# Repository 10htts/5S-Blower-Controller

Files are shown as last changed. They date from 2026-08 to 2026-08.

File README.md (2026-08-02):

# 5S Blower Controller

Open-source reference controller for a two-wire brushed-DC blower powered by a removable 5-series lithium-ion battery (approximately 15–21 V). The design uses a protected low-side N-MOSFET PWM stage, soft start, trigger filtering, voltage/current/temperature protection, an external physical fuse, and a latched fault requiring trigger release.

**Status: CAD CHECKS PASS; NOT YET APPROVED TO ORDER.** KiCad 10 reports zero DRC violations, zero unconnected items, zero schematic-parity issues, and zero ERC errors or warnings. The PCBWay review ZIP is generated, but motor, fuse, mechanical, transient, thermal, and first-article validation remain open. No regulatory certification is claimed.

See [architecture](docs/architecture.md), [wiring](docs/wiring.md), [safety](docs/safety.md), and [revision status](docs/revision-status.md). Firmware tests are host-side and do not replace hardware bring-up.

## Open and edit in KiCad

Open `hardware/blower-controller.kicad_pro` using **File → Open Existing Project** in KiCad. The project contains the editable schematic and PCB.

The canonical KiCad files are generated by `scripts/build_board.py`. A later regeneration will overwrite direct edits to the generated schematic and PCB, so save experimental manual edits under a different project name or port accepted changes into the generator and routing-repair sources.

## Rebuild and export

Run the deterministic board build with KiCad's bundled Python, then generate the current PCBWay review package:

```powershell
& "C:\Program Files\KiCad\10.0\bin\python.exe" scripts\build_board.py
python scripts\export_manufacturing.py --kicad-cli "C:\Program Files\KiCad\10.0\bin\kicad-cli.exe"
```

The current package is `manufacturing/pcbway-review-revC.zip`. It is suitable for PCBWay's Gerber viewer or quotation review, not authorization to place an order.

## Licensing

Hardware is licensed under CERN-OHL-S-2.0 (`LICENSE`). Firmware is GPLv3-or-later (`firmware/LICENSE`).

## Planned validation

Measure stall/start/run current, battery connector polarity, motor inductance, housing fit, fuse interruption behavior, and thermal rise before selecting production thresholds or ordering PCBs.

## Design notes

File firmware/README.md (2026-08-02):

# Firmware

Host-testable reference state machine. Build with a C++17 compiler when targeting hardware; constants are centralized in `src/config.h`. The controller retains soft-start progress across calls, latches protection trips until trigger release, applies the configured undervoltage restart hysteresis, and fails safe on invalid engineering inputs.

`Inputs::trigger` is normalized active-high. The board input is electrically active-low, so the target-specific hardware layer must debounce and invert the pin before calling `Controller::step`. That layer must also configure PWM safe-off at reset, the ATtiny1616 watchdog and brown-out detector, ADC scaling/filtering, periodic scheduling, and gate-output shutdown on missed deadlines. Those target-specific pieces and the final thresholds remain release blockers; this portable code does not claim a verified MCU image or pinout.

`firmware/tests/controller_test.cpp` exercises the compiled state machine when a C++ compiler is available. The Python test suite skips that executable test on hosts without a compiler; CI and release validation must run it with warnings treated as errors.

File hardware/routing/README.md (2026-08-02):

# Rev C routing source

`revC-freerouting.ses` is the accepted Specctra session produced with official
Freerouting 2.2.4 from the `--power-stage-only` board generated by
`scripts/build_board.py`.

The default board build imports that session and then runs
`scripts/repair_freeroute_candidate.py`. The repair script records the reviewed
track, via, ground-stitch, zone-corridor, and two footprint-placement changes
that close the remaining imported-route gaps. KiCad then refills zones and runs
strict DRC with schematic parity; a failing check stops the build.

The post-route repair also keeps the C12/C16 GND stitch outside the 0603 solder
pads. The build explicitly enables missing-courtyard and track-endpoint centering
on vias as errors before DRC.

This routing source makes the CAD result reproducible. It does not replace the
motor, fuse, thermal, transient, enclosure, or first-article validation required
by `docs/validation-plan.md`.

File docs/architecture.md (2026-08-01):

# Architecture

Battery B+ feeds an external fuse, reverse-polarity protection, TVS and bulk capacitance. The protected rail feeds the motor; the MOSFET low side switches motor current. A recirculation path is placed adjacent to the motor/MOSFET loop. A regulator powers the MCU and gate driver. The original low-current trigger is a filtered logic input with ESD protection.

The MCU architecture is selected provisionally because it makes protection and fault-latching behavior explicit and testable. Hardware gate pull-down/default-off, driver disable, watchdog, brownout, and a physical fuse provide independent protection layers.

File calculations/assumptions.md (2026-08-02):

# Assumptions (reference revision)

| Item | Provisional value | Required evidence |
|---|---:|---|
| Battery | 15–21 V, 5S | pack measurement under load and charger-state review |
| Continuous current | 25 A | measured running current |
| Startup current | 40 A or more | current probe |
| PWM | 20 kHz | firmware configuration |
| UV trip/restart | 15.0/16.5 V | system test |
| Overcurrent trip | 40 A | measured trip latency, shunt pulse, and motor waveform |
| MOSFET shutdown | 90 °C sensor | sensor-to-junction correlation and enclosure thermal test |
| Copper | 2 oz target | fabricator stackup and measured temperature rise |
| Board envelope | 77 × 62 mm CAD outline | enclosure and adapter fit check |

Values are not production limits until measured.

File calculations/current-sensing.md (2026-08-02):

# Current sensing

RS1 is a 2 mΩ, 3 W metal-strip shunt with split-pad Kelvin routing to an INA180A2 nominal-gain-50 amplifier. Ideal values are:

| Current | Shunt voltage | Shunt power | Ideal amplifier output |
|---:|---:|---:|---:|
| 25 A | 50 mV | 1.25 W | 2.5 V |
| 30 A | 60 mV | 1.80 W | 3.0 V |
| 40 A | 80 mV | 3.20 W | 4.0 V |

At 40 A the ideal shunt dissipation exceeds its 3 W nominal rating, so the firmware's provisional 40 A trip cannot be treated as a continuous-current rating. Validate shunt pulse energy, tolerance, temperature coefficient, amplifier offset/gain error and output swing, ADC reference/scaling, filtering delay, and trip latency from measured motor waveforms. Firmware limiting never replaces the external fuse.

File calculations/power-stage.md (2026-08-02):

# Power-stage comparison

## A: MCU low-side PWM (selected reference architecture)

An MCU drives a TC4422A gate driver from a nominal 9.98 V rail and two parallel IPT015N10N5 100 V N-channel MOSFETs. A Kelvin-connected 2 mΩ shunt provides current feedback; an SMDJ33A TVS, local bulk ceramic/electrolytic capacitance, and an STPS41H100C recirculation diode manage supply and switching energy. This architecture supports filtered UV, current, thermal, watchdog, and trigger-release behavior in one testable state machine.

## B: analog controller (rejected for the reference)

An oscillator, ramp comparator, current-limit comparator, and UV/thermal shutdown can reduce firmware cost, but threshold interaction, restart latching, and diagnostic coverage become less transparent. It is only attractive after measured current and thermal requirements justify a simpler fixed-function design.

## Loss screening

The selected MOSFET is specified at a maximum 1.5 mΩ at 10 V gate drive and 25 °C. Two ideal, equally sharing devices therefore have a screening resistance of 0.75 mΩ. DC conduction-only estimates are:

| Total current | Ideal pair loss |
|---:|---:|
| 10 A | 0.075 W |
| 20 A | 0.300 W |
| 25 A | 0.469 W |
| 30 A | 0.675 W |
| 40 A | 1.200 W |

These figures are not thermal predictions. They exclude hot `RDS(on)`, current-sharing error, switching overlap, diode loss, gate-drive loss, shunt loss, copper loss, and motor ripple. Recalculate with measured waveforms and datasheet worst cases, and verify VDS/VGS transients and SOA before release.

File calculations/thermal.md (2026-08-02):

# Thermal review

Measure MOSFET case and PCB temperature with thermocouples during steady operation and repeated starts at currents justified by the measured motor. Include hot `RDS(on)`, switching loss, current-sharing error, diode loss, copper/via spreading, capacitor ripple, connector and wire heating, enclosure airflow, and shunt heating.

The firmware's provisional 90 °C sensor trip is a protection target, not a demonstrated component-junction or touch-temperature limit. Correlate the sensor reading with the hottest MOSFET junction estimate and all nearby components in the final enclosure. Define allowable ambient temperature, duty cycle, cooldown behavior, and thermal margin before first-article testing.

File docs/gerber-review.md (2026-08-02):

# Gerber review record — Rev C CAD review

Generated with KiCad 10.0.5 on 2026-08-02. The current archive is `manufacturing/pcbway-review-revC.zip`. It contains F.Cu, B.Cu, solder-mask, paste, silkscreen, Edge.Cuts, Excellon drill and drill-map files, PCB and schematic PDFs, placement CSV, BOM, DRC/ERC reports, board renders, and release notes.

The top and bottom 3D renders, fabrication PDF, and both copper-layer plots were visually inspected. The generated outline is 77 × 62 mm. The external connections are labelled, the outline and holes are present, and no obvious missing copper layer or gross plot defect was observed. KiCad reports zero DRC violations, zero unconnected items, zero schematic-parity issues, and zero ERC errors or warnings. Courtyard presence/overlap and track endpoints centered on vias are active DRC checks.

This review establishes CAD consistency only. It does not establish current capacity, transient margin, fuse coordination, component thermal limits in the enclosure, mechanical fit, EMI behavior, or assembly correctness. The package remains a **quotation/viewer review artifact only**, not authorization to place an order. Complete `docs/validation-plan.md` and obtain an independent Gerber and electrical review before changing that status.

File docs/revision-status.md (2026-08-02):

# Revision status — Rev C

**NOT YET APPROVED TO ORDER.** The CAD and export pipeline are complete and clean; the remaining blockers require real component, motor, mechanical, and first-article evidence.

| Release gate | Status | Evidence or remaining work |
|---|---|---|
| Deterministic schematic/PCB generation | PASS | `scripts/build_board.py` reproduces the canonical routed board from the accepted session plus reviewed repairs. |
| KiCad PCB checks | PASS | 0 DRC violations, 0 unconnected items, 0 schematic-parity issues with KiCad 10.0.5; missing-courtyard and off-center-via-track checks are enabled as errors. |
| KiCad schematic checks | PASS | 0 ERC errors and 0 warnings. |
| Repository and firmware host checks | PASS | Design checker and host unit tests pass. Target MCU integration remains a separate gate. |
| Fabrication plots and visual CAD review | PASS | Rev C Gerbers, drill, PDFs, renders, reports, BOM, and placement files generated and visually reviewed. |
| PCBWay quotation/viewer package | PASS | `manufacturing/pcbway-review-revC.zip` is suitable for independent file review. |
| PCBA procurement/process package | BLOCKED | BOM has unresolved MPN/supplier data; 15 drilled via locations intersect SMD pad copper and need an approved dogbone or filled/capped process; every footprint and placement orientation still needs assembly review. |
| Target firmware and fail-safe behavior | BLOCKED | Implement and verify HAL, active-low trigger inversion, ADC scaling/filtering, PWM-safe reset, watchdog, brownout, and scheduling on the selected MCU. |
| Motor and wiring characterization | BLOCKED | Measure running, starting, and stall current at 15/18/21 V, motor inductance, lead resistance/length, and wire/connector ratings. |
| Fuse and protection coordination | BLOCKED | Select the exact external fuse and prove time-current/I²t coordination with wiring, TVS, MOSFET, shunt, and motor faults. |
| Mechanical fit | BLOCKED | Confirm the 77 × 62 mm outline, holes, connector locations, polarity, terminal geometry, and component-height keepouts against the enclosure and battery adapter. |
| Transient, thermal, and EMI validation | BLOCKED | Measure switch-node, drain, gate, and supply transients; temperatures in the final enclosure; conducted/radiated noise; and repeated start/fault cycles. |
| First-article release | BLOCKED | Assemble and inspect a fused prototype, complete `docs/bring-up.md`, and record signed results for every validation gate. |

The clean DRC/ERC result is necessary but is not proof that the board can safely carry an unknown motor current or survive an unknown enclosure and fuse system.

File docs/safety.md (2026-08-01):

# Safety

This board switches high current from lithium-ion packs and can produce fire, arc, hot copper, and unexpected motor motion. Use a current-limited bench supply for first power-up, an external fuse, eye protection, guarded wiring, and a physical disconnect. Never bypass the fuse or rely on the OEM battery protection. Stop immediately for abnormal heating, smell, smoke, or uncontrolled rotation.

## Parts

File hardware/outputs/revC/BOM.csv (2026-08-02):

References | Value | Footprint | Manufacturer Part Number | LCSC | Quantity | DNP
C1,C2 | 470u 63V | Capacitor_THT:CP_Radial_D12.5mm_P5.00mm | UPW1J471MHD | UNVERIFIED | 2
C3-C5 | 4u7 100V X7S | Capacitor_SMD:C_1210_3225Metric | C3225X7S2A475K200AE | UNVERIFIED | 3
C6 | 100n 100V | Capacitor_SMD:C_0603_1608Metric |  | UNVERIFIED | 1
C7,C10 | 4u7 25V X7R | Capacitor_SMD:C_1206_3216Metric |  | UNVERIFIED | 2
C8,C13,C15-C17,C19 | 100n 25V | Capacitor_SMD:C_0603_1608Metric |  | UNVERIFIED | 6
C9 | 1u 100V X7S | Capacitor_SMD:C_1210_3225Metric |  | UNVERIFIED | 1
C11,C12,C14 | 1u 25V | Capacitor_SMD:C_0603_1608Metric |  | UNVERIFIED | 3
C18 | 1n 50V C0G | Capacitor_SMD:C_0603_1608Metric |  | UNVERIFIED | 1
D1 | SMDJ33A | Diode_SMD:D_SMC | SMDJ33A | UNVERIFIED | 1
D2 | STPS41H100CG | Package_TO_SOT_SMD:TO-263-3_TabPin2 | STPS41H100CG-TR | UNVERIFIED | 1
D3 | PESD5V0S1BA | Diode_SMD:D_SOD-323 | PESD5V0S1BA,115 | C19224 | 1
D4 | S1M | Diode_SMD:D_SMA | S1M (onsemi) | C232826 | 1
J6 | UPDI | Connector_PinHeader_2.54mm:PinHeader_1x03_P2.54mm_Vertical |  | UNVERIFIED | 1
LED1 | GREEN | LED_SMD:LED_0603_1608Metric | 19-217/GHC-YR1S2/3T | C72043 | 1
Q1,Q2 | IPT015N10N5 | Package_TO_SOT_SMD:Infineon_PG-HSOF-8-1 | IPT015N10N5ATMA1 | C108964 | 2
R1 | 100k 1% | Resistor_SMD:R_0603_1608Metric |  | UNVERIFIED | 1
R2 | 18k 1% | Resistor_SMD:R_0603_1608Metric |  | UNVERIFIED | 1
R3,R4 | 4R7 | Resistor_SMD:R_0805_2012Metric |  | UNVERIFIED | 2
R6,R12,R13 | 100k | Resistor_SMD:R_0603_1608Metric |  | UNVERIFIED | 3
R7,R8 | 10k | Resistor_SMD:R_0603_1608Metric |  | UNVERIFIED | 2
R9 | 10k 1% | Resistor_SMD:R_0603_1608Metric |  | UNVERIFIED | 1
R10 | 100R | Resistor_SMD:R_0603_1608Metric |  | UNVERIFIED | 1
R11 | 1k | Resistor_SMD:R_0603_1608Metric |  | UNVERIFIED | 1
R14 | 97k6 1% | Resistor_SMD:R_0603_1608Metric |  | UNVERIFIED | 1
R15 | 13k0 1% | Resistor_SMD:R_0603_1608Metric |  | UNVERIFIED | 1
RS1 | 2m0 3W | Resistor_SMD:R_Shunt_Vishay_WSR2_WSR3_KelvinConnection | WSR32L000FEA | UNVERIFIED | 1
TH1 | NTC 10k B3380 | Resistor_SMD:R_0603_1608Metric | NCP18XH103F03RB | C13564 | 1
U1 | ATtiny1616 | Package_SO:SOIC-20W_7.5x12.8mm_P1.27mm | ATTINY1616-SNR | C614136 | 1
U2 | TC4422AVOA | Package_SO:SOIC-8_3.9x4.9mm_P1.27mm | TC4422AVOA | C37183 | 1
U3 | TPS7A4001 | Package_SO:MSOP-8-1EP_3x3mm_P0.65mm_EP1.68x1.88mm | TPS7A4001DGNR | C55006 | 1
U4 | MCP1703A-5002E/DB | Package_TO_SOT_SMD:SOT-223-3_TabPin2 | MCP1703A-5002E/DB | UNVERIFIED | 1
U5 | INA180A2 | Package_TO_SOT_SMD:SOT-23-5 | INA180A2IDBVR | C192764 | 1

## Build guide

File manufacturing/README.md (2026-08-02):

# Manufacturing

The repository includes a KiCad 10 export script. It updates Gerbers, Excellon drills, PCB/schematic PDFs, reports, and the ZIP package only after DRC with schematic parity, ERC, and required fabrication-layer checks pass. On failure it writes fresh reports and a blocked status, but leaves older output directories and archives untouched.

Run from the repository root:

```powershell
python scripts/export_manufacturing.py --kicad-cli "C:\Program Files\KiCad\10.0\bin\kicad-cli.exe"
```

The current Rev C CAD export passes DRC and ERC. Its current review artifacts are:

- `hardware/outputs/revC/`
- `manufacturing/pcbway-review-revC.zip`

The ZIP may be uploaded to PCBWay's viewer or quotation workflow for an independent file review. It is **not approved for ordering**: exact mechanical fit, motor current and inductive transients, fuse coordination, enclosure thermal performance, and first-article tests are still missing. PCBWay assembly is additionally blocked by incomplete procurement data in the BOM. See `manufacturing/pcbway/README.md` and `docs/revision-status.md`.

Older `revA` outputs are superseded and must not be used for a new quote or order.

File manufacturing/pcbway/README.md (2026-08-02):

# PCBWay review package

Use only `manufacturing/pcbway-review-revC.zip`. The archive is a **CAD-clean review package**, not an orderable release. Treat it as stale whenever the export command exits nonzero. The current source has a populated schematic and clean KiCad DRC/ERC reports, including schematic parity; remaining blocks are physical and procurement validation, not CAD connectivity.

The archive contains Gerbers for F.Cu/B.Cu, solder mask, silkscreen, paste, and Edge.Cuts; an Excellon drill file and drill map; BOM and XY placement CSV files; PCB and schematic PDFs; DRC/ERC reports; renders; and fabrication/status notes.

Before authorizing an order:

1. Confirm the 77 × 62 mm outline, mounting holes, connector locations, terminal polarity, component heights, and enclosure clearances against measured mechanical data.
2. Confirm the intended copper weight, thickness, finish, material, and any panelization with the fabricator.
3. Review every Gerber and drill layer in PCBWay's viewer and obtain an independent electrical/layout review.
4. Complete the motor, fuse, transient, thermal, EMI, and first-article gates in `docs/validation-plan.md`.
5. For assembly, resolve every part flagged in `MANUFACTURING-STATUS.txt`, review `VIA-IN-PAD-REVIEW.txt`, choose an approved dogbone or filled/capped via-in-pad process, and verify BOM/placement orientation against manufacturer datasheets.

The external fuse is mandatory. This board accepts only B+ and B− from the battery; it is not a charger or BMS.

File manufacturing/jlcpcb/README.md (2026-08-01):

Populate after ERC/DRC and final component/footprint verification. No orderable release is present.

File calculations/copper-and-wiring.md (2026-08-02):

# Copper and wiring

The current PCB uses wide power zones on both layers, stitching vias, a compact switching loop, and Kelvin shunt traces. KiCad DRC confirms geometric connectivity and configured clearances; it does not establish ampacity or temperature rise.

Two-ounce copper is the provisional fabrication target, not a validated minimum. Confirm finished copper thickness with the fabricator and calculate/measure copper and via temperature rise from the actual continuous and transient motor current. Validate solder volume, pad geometry, connector and wire gauge, lead length, voltage drop, strain relief, enclosure clearances, and external fuse placement before release.

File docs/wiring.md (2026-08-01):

# Wiring

Only connect the battery to `B+` and `B-`; do not connect cell taps. Connect the two motor wires to `M+` and `M-`, and the original low-current trigger to `TRIGGER` and logic ground as verified with a meter. Polarity and connector pinout are not yet verified for any specific blower.

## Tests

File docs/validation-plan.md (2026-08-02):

# Validation plan

Record the board serial/revision, test date, operator, equipment model, probe arrangement, instrument settings, supply limits, ambient temperature, firmware version, raw captures, and pass/fail decision for every test. Agree on numerical acceptance limits before testing; do not derive a limit after seeing the result.

## Before a fabrication order

1. Independently review the schematic, PCB, DRC/ERC reports, Gerbers, drill file, and footprint/polarity mapping.
2. Measure the battery adapter and enclosure. Confirm the 77 × 62 mm outline, holes, terminals, polarity, component heights, insulation, creepage around exposed conductors, airflow, and service access.
3. Characterize the exact motor at 15, 18, and 21 V: steady running current, start waveform, restrained/locked-rotor current with a safe current limit, lead resistance, and inductance.
4. Select the exact external fuse, connector, and wire. Review voltage/current ratings and coordinate fuse time-current and I²t behavior with the TVS, shunt, MOSFETs, diode, copper, and worst credible fault.
5. Recalculate hot MOSFET conduction/switching loss, shunt pulse/steady loss, diode loss, copper/via rise, bulk-capacitor ripple, and transient margin using the measured motor data.

## First-article electrical tests

1. Follow `docs/bring-up.md` from a current-limited bench supply with the motor disconnected, then with a fused and restrained motor.
2. Verify battery and logic rails, reset gate-off state, PWM frequency/dead behavior, gate amplitude, ADC scaling, trigger polarity, soft-start monotonicity, and trigger-release restart.
3. Capture B+, MOSFET VDS, both VGS waveforms, switch node, shunt current, and regulator rails during connection, start, stop, stall/fault, and fuse interruption. Compare every peak with component absolute maximums plus an approved engineering margin.
4. Verify undervoltage trip/restart under slow ramps and battery sag, overcurrent response, overtemperature response, invalid-sensor fail-safe behavior, watchdog reset, brownout reset, and repeated power cycling.

## Thermal, endurance, and integration tests

1. Measure MOSFET, shunt, diode, TVS, connectors, wires, capacitors, regulators, and PCB temperatures in the final enclosure at the approved duty cycle and worst ambient condition.
2. Run repeated starts, stops, stalls/faults, UV events, and long-duration operation while checking for drift, nuisance trips, damaged copper, connector heating, or uncontrolled restart.
3. Check conducted and radiated noise in the final wiring/enclosure configuration and verify that switching does not corrupt trigger, ADC, or programming interfaces.
4. Inspect the first article after testing and archive photographs, waveforms, temperatures, firmware, and a signed release checklist.

No board is order-approved until every applicable item has objective evidence and an approved pass criterion.

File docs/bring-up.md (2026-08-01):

# Bring-up

1. Inspect polarity, shorts, solder bridges, MOSFET orientation, shunt Kelvin routing, and gate pull-down.
2. Power logic from a current-limited supply with the motor disconnected; verify reset leaves the gate off.
3. Verify ADC scaling and trigger release/fault behavior with simulated inputs.
4. Use a fused, current-limited supply and a restrained motor; begin with a low current limit and short duty cycle.
5. Increase load only while recording current, VBUS, gate waveform, MOSFET/shunt temperature, and fault response.

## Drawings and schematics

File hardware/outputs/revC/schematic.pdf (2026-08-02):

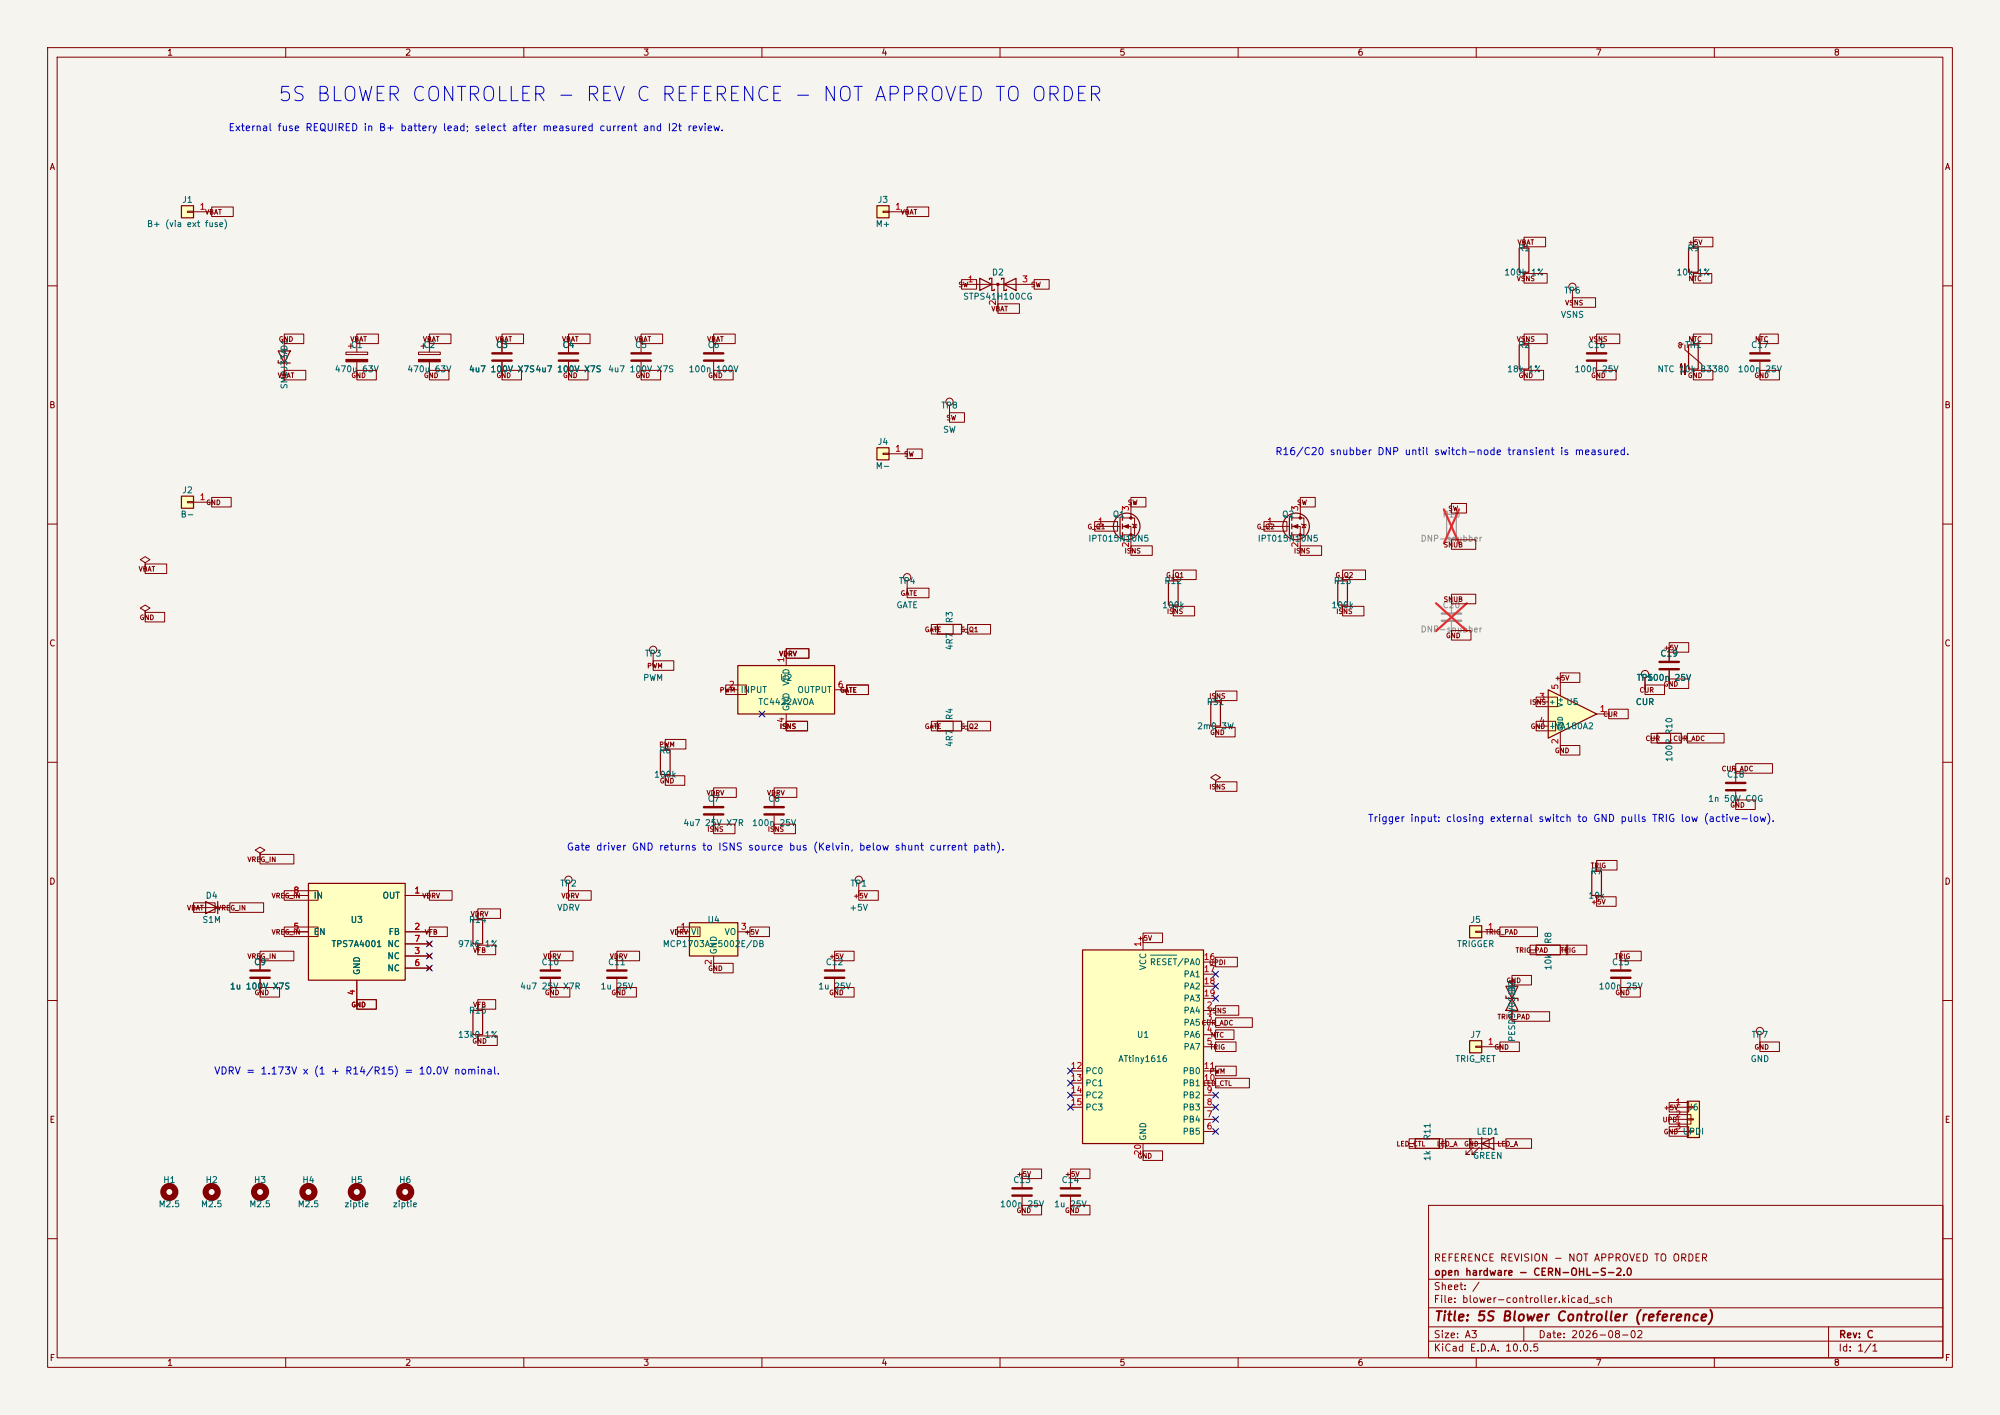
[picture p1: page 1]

5S BLOWER CONTROLLER - REV C REFERENCE - NOT APPROVED TO ORDER

External fuse REQUIRED in B+ battery lead; select after measured current and I2t review.

R16/C20 snubber DNP until switch-node transient is measured.

R16 DNP-snubber C20 DNP-snubber C10

Trigger input: closing external switch to GND pulls TRIG low (active-low).

Gate driver GND returns to ISNS source bus (Kelvin, below shunt current path).

REFERENCE REVISION - NOT APPROVED TO ORDER
open hardware - CERN-OHL-S-2.0
Sheet: /
File: blower-controller.kicad_sch
Title: 5S Blower Controller (reference)

Size: A3 | Rev: C | F Date: 2026-08-02
KiCad E.D.A. 10.0.5 | Id: 1/1

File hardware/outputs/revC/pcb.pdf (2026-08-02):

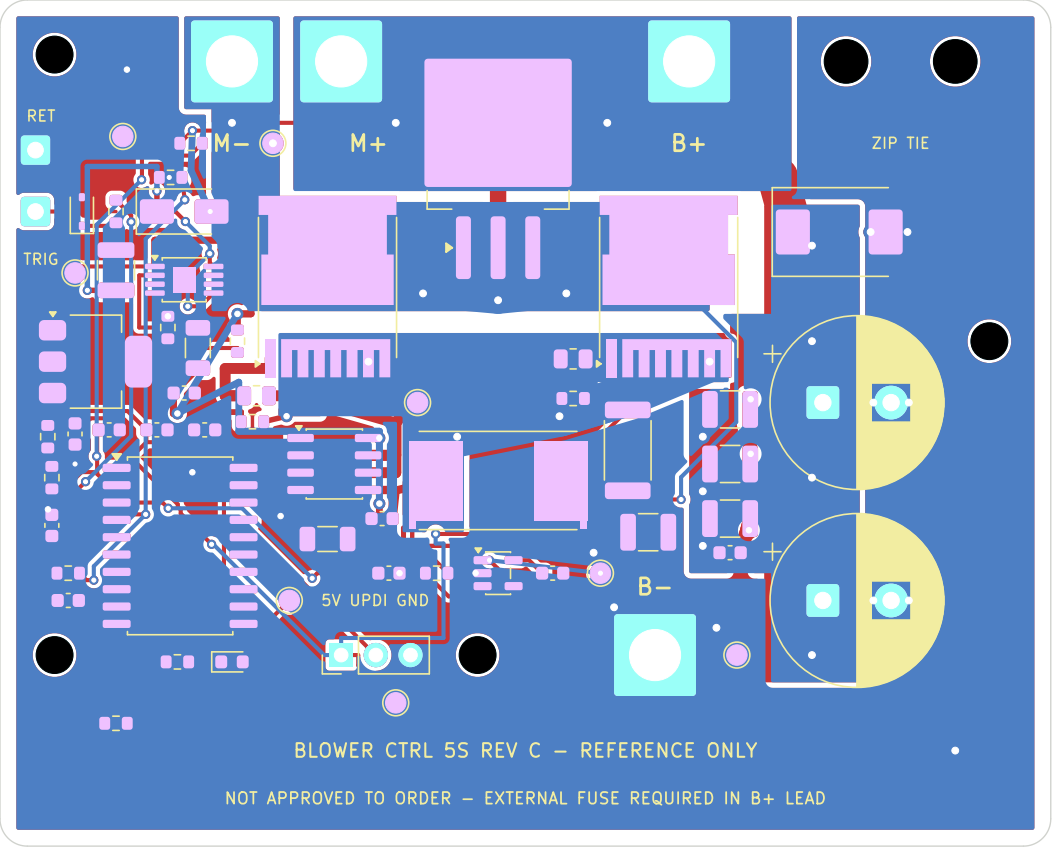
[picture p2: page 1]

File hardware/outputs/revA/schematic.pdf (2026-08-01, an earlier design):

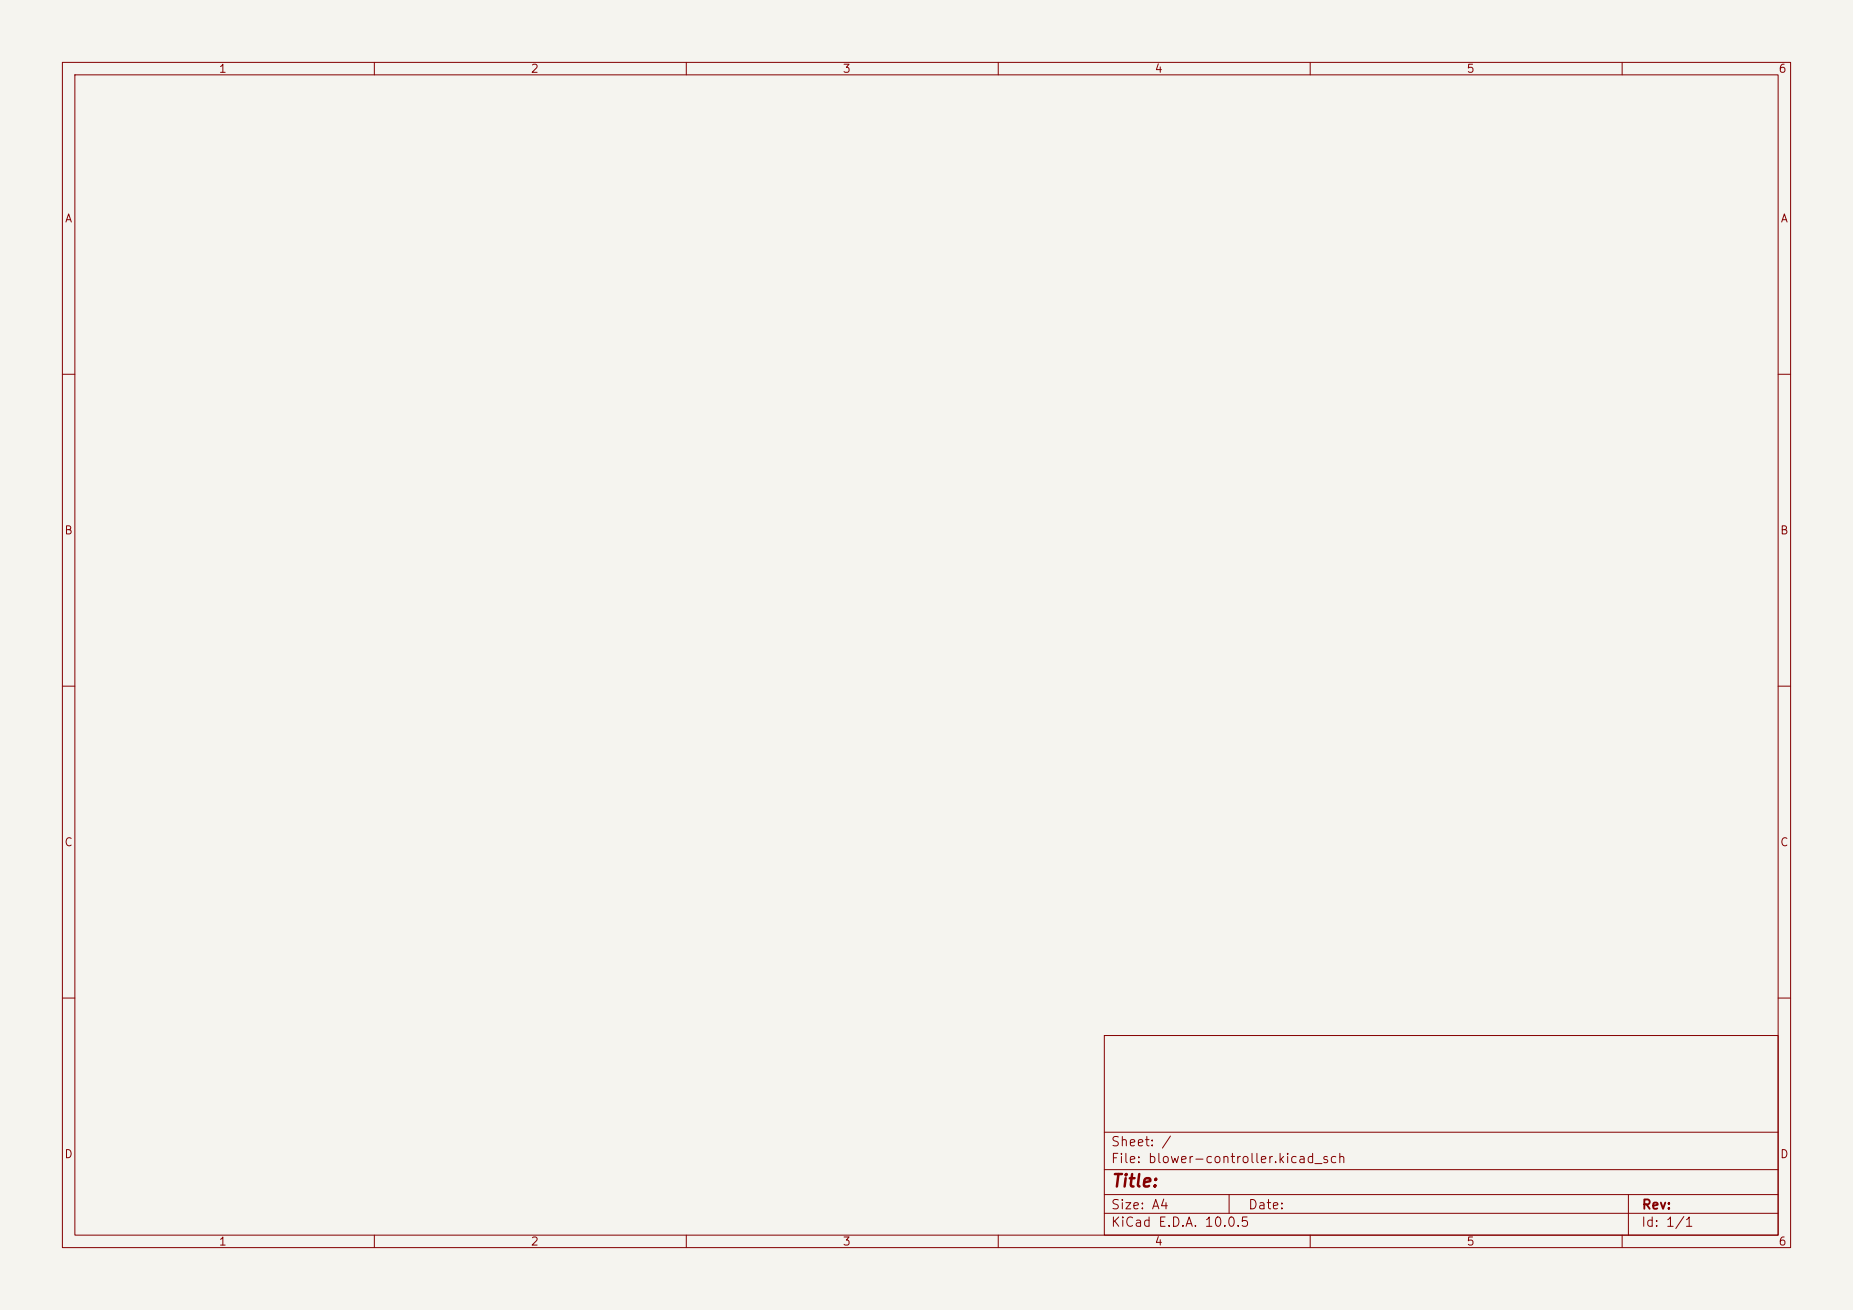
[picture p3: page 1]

Size: A4 | Rev:
KiCad E.D.A. 10.0.5 | Id: 1/1

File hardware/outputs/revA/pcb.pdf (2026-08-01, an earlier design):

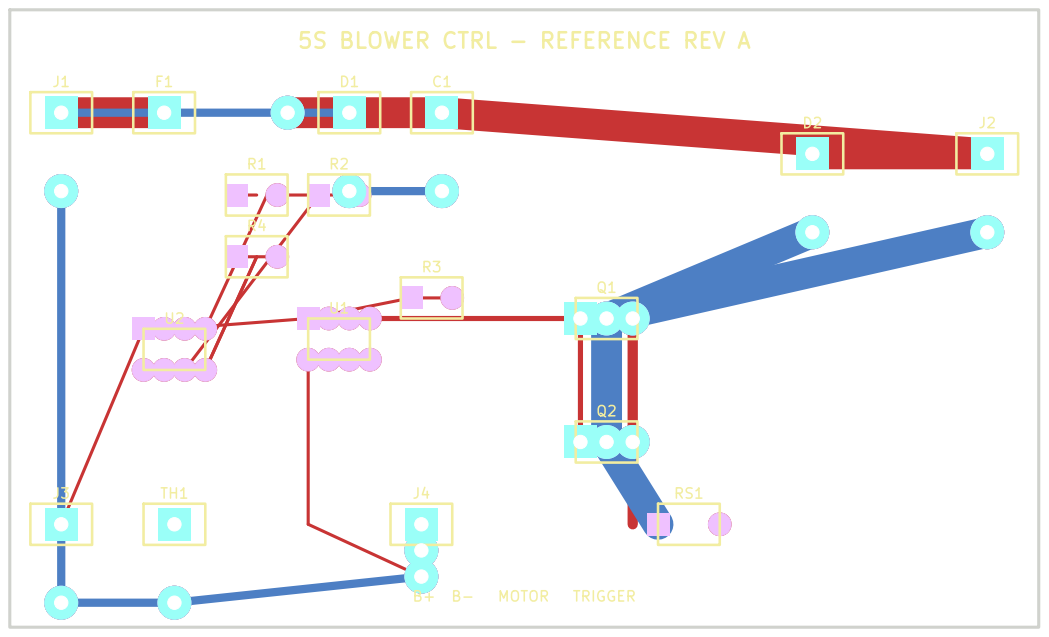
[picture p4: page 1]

5S BLOWER CTRL - REFERENCE REV A

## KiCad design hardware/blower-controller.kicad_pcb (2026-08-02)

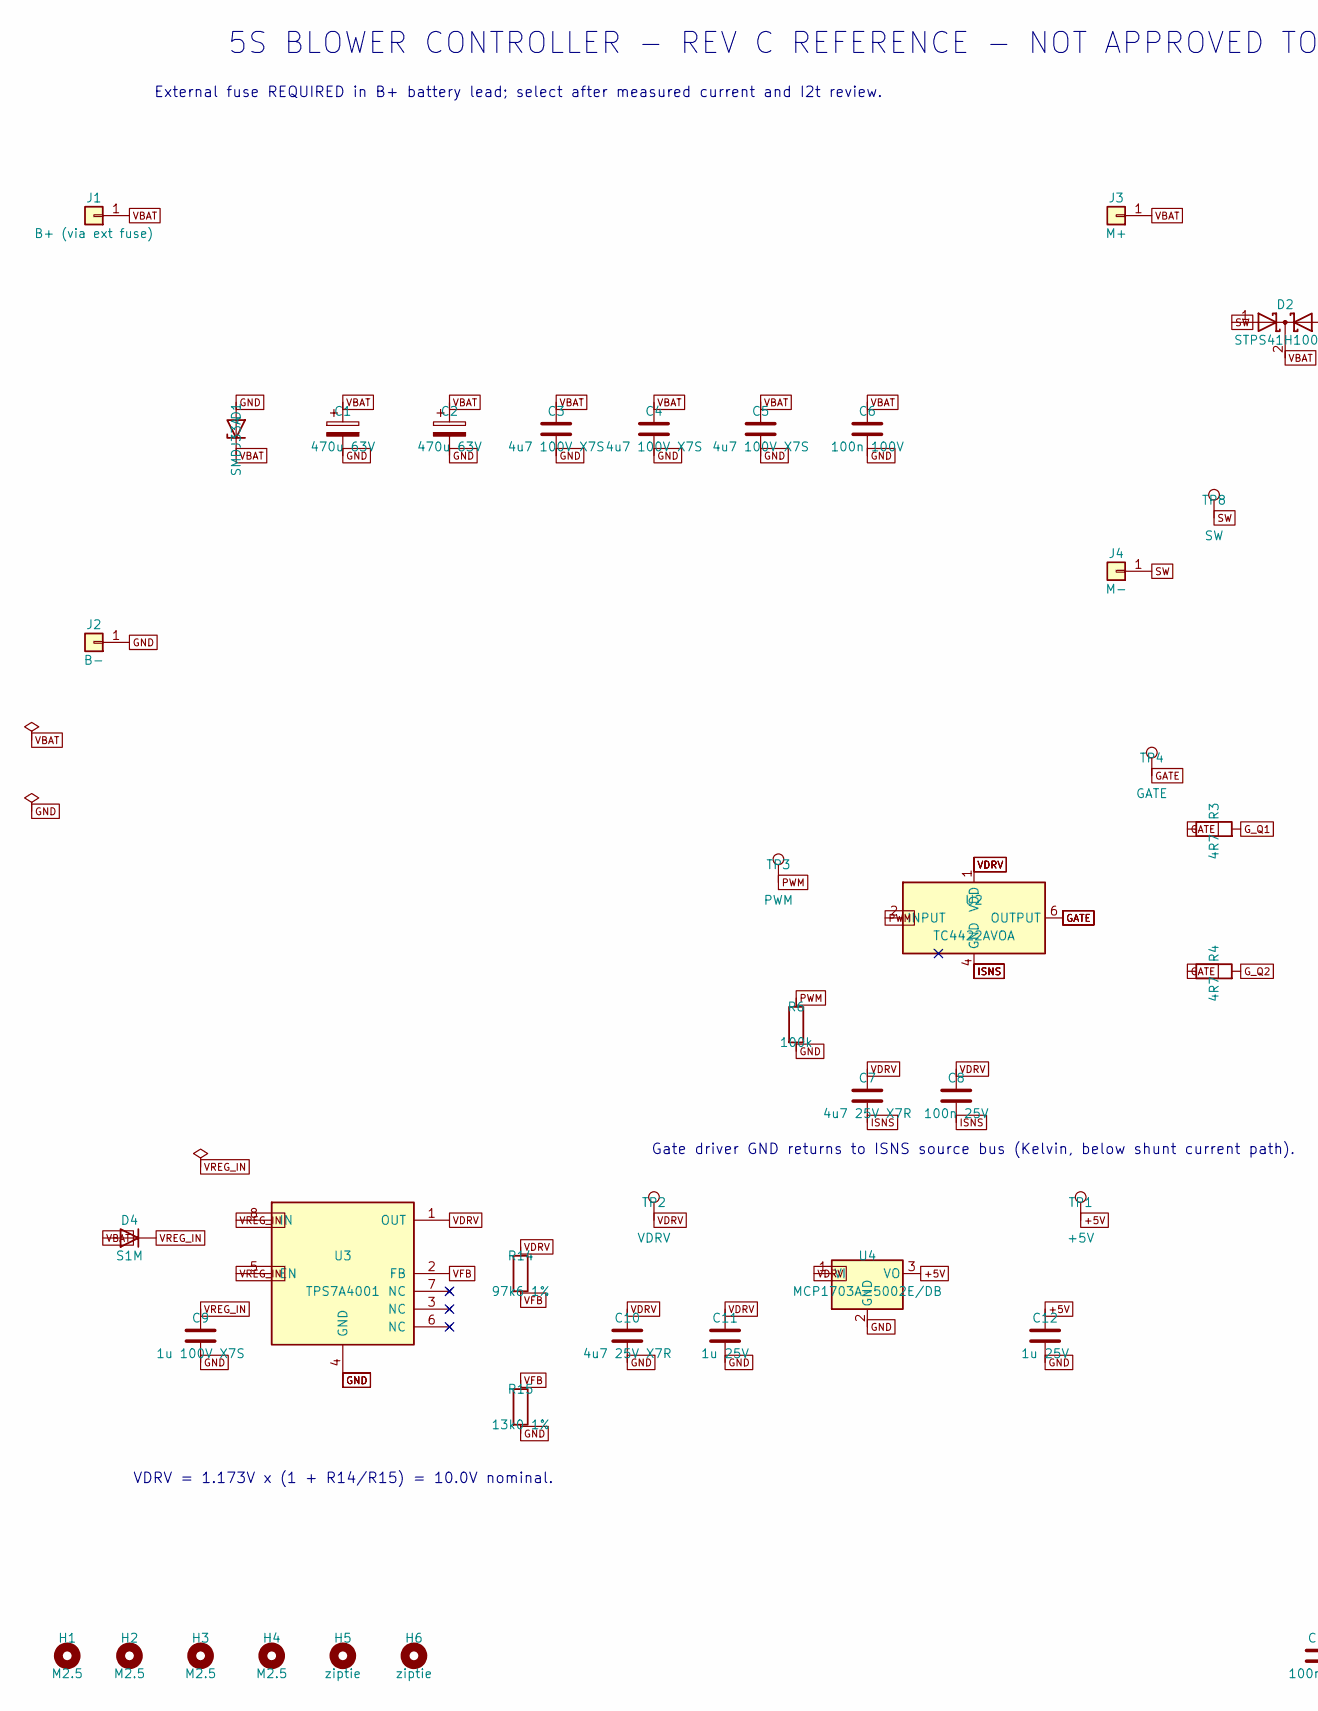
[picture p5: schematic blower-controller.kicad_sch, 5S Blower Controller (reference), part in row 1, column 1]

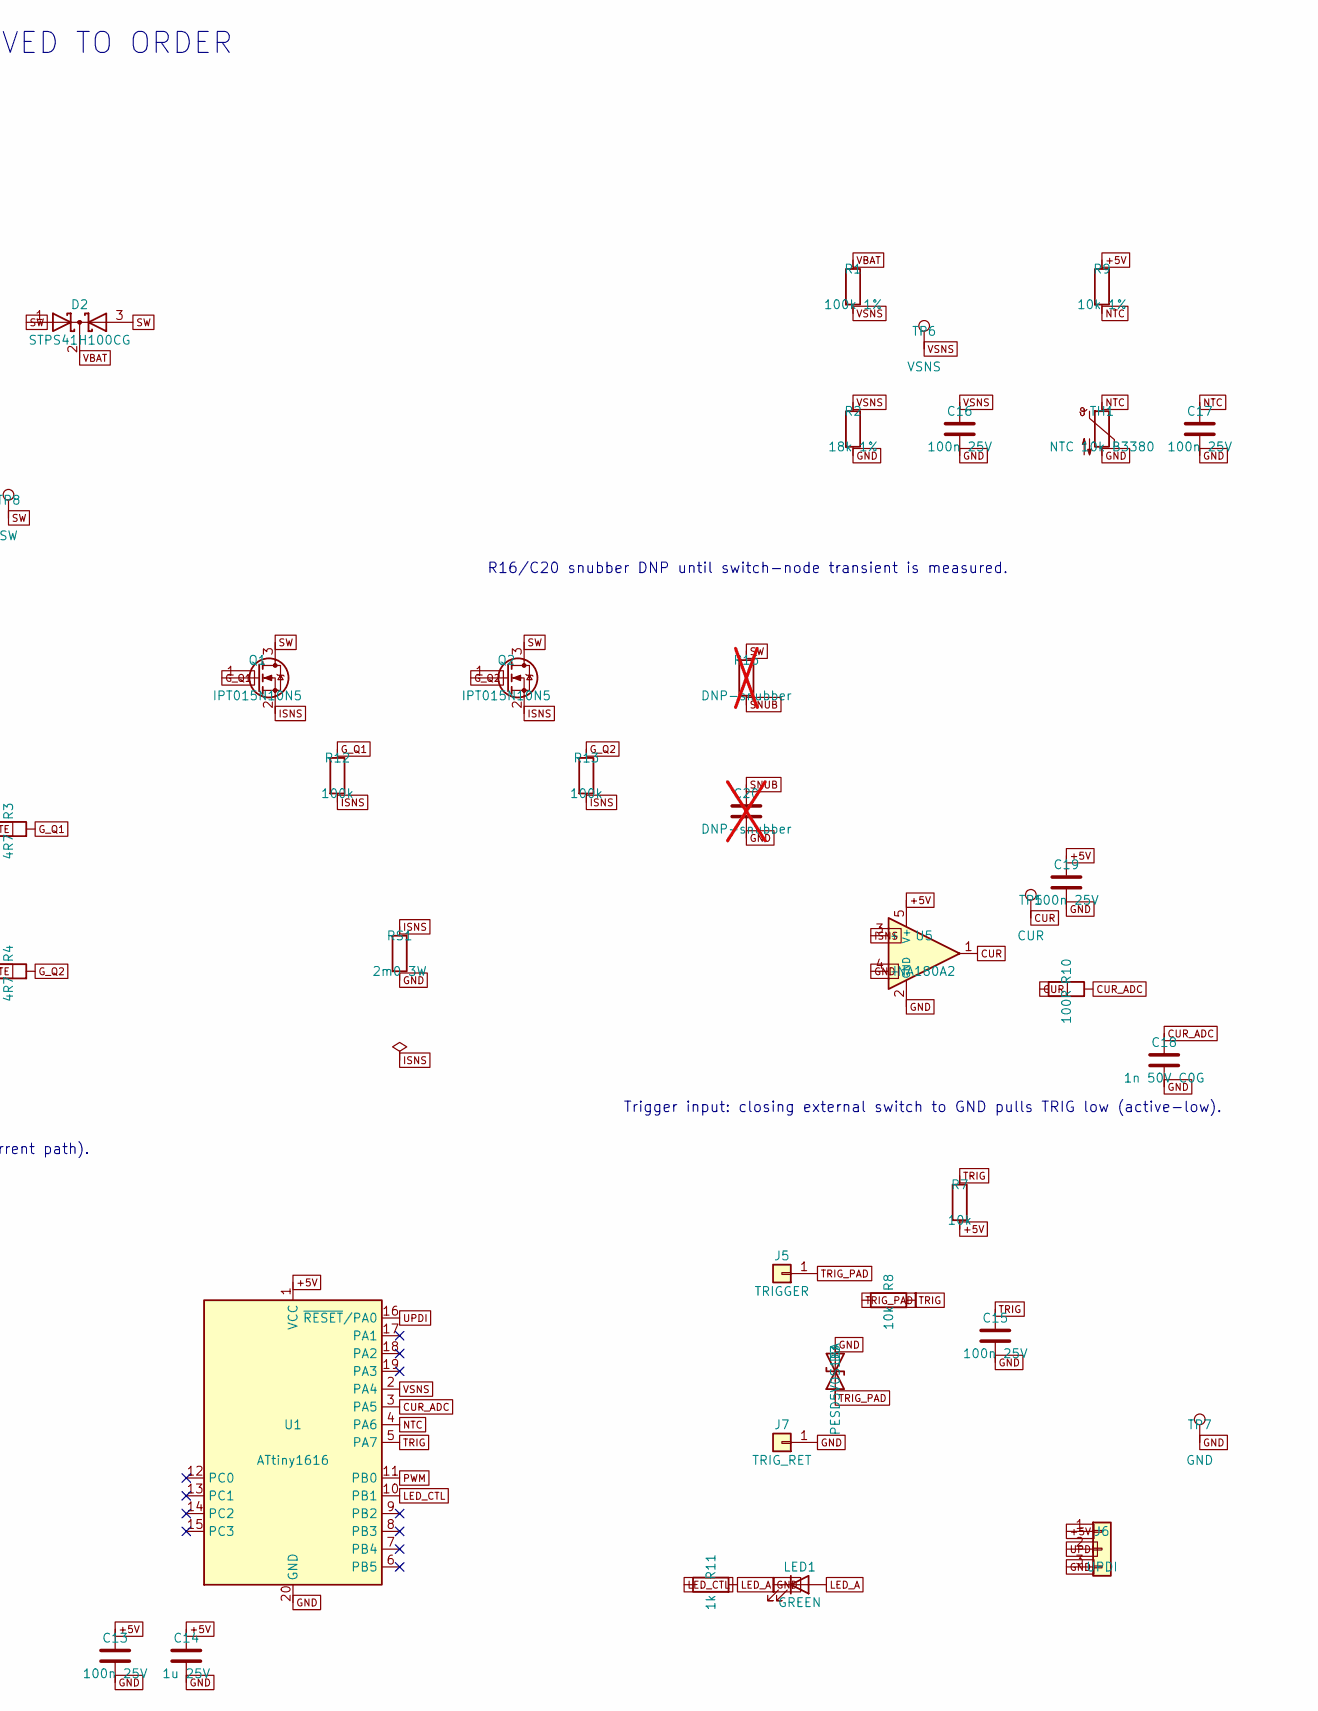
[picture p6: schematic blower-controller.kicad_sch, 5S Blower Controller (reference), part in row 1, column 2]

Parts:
C1, C2: 470u 63V; CP_Radial_D12.5mm_P5.00mm; MPN UPW1J471MHD; LCSC UNVERIFIED
C3, C4, C5: 4u7 100V X7S; C_1210_3225Metric; MPN C3225X7S2A475K200AE; LCSC UNVERIFIED
C6: 100n 100V; C_0603_1608Metric; LCSC UNVERIFIED
C7, C10: 4u7 25V X7R; C_1206_3216Metric; LCSC UNVERIFIED
C8, C13, C15, C16, C17, C19: 100n 25V; C_0603_1608Metric; LCSC UNVERIFIED
C9: 1u 100V X7S; C_1210_3225Metric; LCSC UNVERIFIED
C11, C12, C14: 1u 25V; C_0603_1608Metric; LCSC UNVERIFIED
C18: 1n 50V C0G; C_0603_1608Metric; LCSC UNVERIFIED
C20: DNP-snubber; C_1210_3225Metric; LCSC UNVERIFIED; not fitted
D1: SMDJ33A; D_SMC; MPN SMDJ33A; LCSC UNVERIFIED
D2: STPS41H100CG; TO-263-3_TabPin2; MPN STPS41H100CG-TR; LCSC UNVERIFIED
D3: PESD5V0S1BA; D_SOD-323; MPN PESD5V0S1BA,115; LCSC C19224
D4: S1M; D_SMA; MPN S1M (onsemi); LCSC C232826
H1, H2, H3, H4: M2.5; MountingHole_2.7mm_M2.5; LCSC UNVERIFIED
H5, H6: ziptie; MountingHole_3.2mm_M3; LCSC UNVERIFIED
J1: B+ (via ext fuse); SolderWire-4sqmm_1x01_D3mm_OD6mm; LCSC UNVERIFIED
J2: B-; SolderWire-4sqmm_1x01_D3mm_OD6mm; LCSC UNVERIFIED
J3: M+; SolderWire-4sqmm_1x01_D3mm_OD6mm; LCSC UNVERIFIED
J4: M-; SolderWire-4sqmm_1x01_D3mm_OD6mm; LCSC UNVERIFIED
J5: TRIGGER; SolderWire-0.5sqmm_1x01_D0.9mm_OD2.1mm; LCSC UNVERIFIED
J6: UPDI; PinHeader_1x03_P2.54mm_Vertical; LCSC UNVERIFIED
J7: TRIG_RET; SolderWire-0.5sqmm_1x01_D0.9mm_OD2.1mm; LCSC UNVERIFIED
LED1: GREEN; LED_0603_1608Metric; MPN 19-217/GHC-YR1S2/3T; LCSC C72043
Q1, Q2: IPT015N10N5; Infineon_PG-HSOF-8-1; MPN IPT015N10N5ATMA1; LCSC C108964
R1: 100k 1%; R_0603_1608Metric; LCSC UNVERIFIED
R2: 18k 1%; R_0603_1608Metric; LCSC UNVERIFIED
R3, R4: 4R7; R_0805_2012Metric; LCSC UNVERIFIED
R6, R12, R13: 100k; R_0603_1608Metric; LCSC UNVERIFIED
R7, R8: 10k; R_0603_1608Metric; LCSC UNVERIFIED
R9: 10k 1%; R_0603_1608Metric; LCSC UNVERIFIED
R10: 100R; R_0603_1608Metric; LCSC UNVERIFIED
R11: 1k; R_0603_1608Metric; LCSC UNVERIFIED
R14: 97k6 1%; R_0603_1608Metric; LCSC UNVERIFIED
R15: 13k0 1%; R_0603_1608Metric; LCSC UNVERIFIED
R16: DNP-snubber; R_2512_6332Metric; LCSC UNVERIFIED; not fitted
RS1: 2m0 3W; R_Shunt_Vishay_WSR2_WSR3_KelvinConnection; MPN WSR32L000FEA; LCSC UNVERIFIED
TH1: NTC 10k B3380; R_0603_1608Metric; MPN NCP18XH103F03RB; LCSC C13564
TP1: +5V; TestPoint_Pad_D1.5mm; LCSC UNVERIFIED
TP2: VDRV; TestPoint_Pad_D1.5mm; LCSC UNVERIFIED
TP3: PWM; TestPoint_Pad_D1.5mm; LCSC UNVERIFIED
TP4: GATE; TestPoint_Pad_D1.5mm; LCSC UNVERIFIED
TP5: CUR; TestPoint_Pad_D1.5mm; LCSC UNVERIFIED
TP6: VSNS; TestPoint_Pad_D1.5mm; LCSC UNVERIFIED
TP7: GND; TestPoint_Pad_D1.5mm; LCSC UNVERIFIED
TP8: SW; TestPoint_Pad_D1.5mm; LCSC UNVERIFIED
U1: ATtiny1616; SOIC-20W_7.5x12.8mm_P1.27mm; MPN ATTINY1616-SNR; LCSC C614136
U2: TC4422AVOA; SOIC-8_3.9x4.9mm_P1.27mm; MPN TC4422AVOA; LCSC C37183
U3: TPS7A4001; MSOP-8-1EP_3x3mm_P0.65mm_EP1.68x1.88mm; MPN TPS7A4001DGNR; LCSC C55006
U4: MCP1703A-5002E/DB; SOT-223-3_TabPin2; MPN MCP1703A-5002E/DB; LCSC UNVERIFIED
U5: INA180A2; SOT-23-5; MPN INA180A2IDBVR; LCSC C192764

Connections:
+5V: C12.1, C13.1, C14.1, C19.1, J6.1, R7.2, R9.1, TP1.1, U1.1 (VCC), U4.3 (VO), U5.5 (V+)
CUR: R10.1, TP5.1, U5.1
CUR_ADC: C18.1, R10.2, U1.3 (PA5)
GATE: R3.1, R4.1, TP4.1, U2.6 (OUTPUT), U2.7 (OUTPUT)
GND: C1.2, C2.2, C3.2, C4.2, C5.2, C6.2, C9.2, C10.2, C11.2, C12.2, C13.2, C14.2, C15.2, C16.2, C17.2, C18.2, C19.2, C20.2, D1.2 (A), D3.2 (A2), J2.1, J6.3, J7.1, LED1.1 (K), R2.2, R6.2, R15.2, RS1.2, TH1.2, TP7.1, U1.20 (GND), U3.4 (GND), U3.9 (EP), U4.2 (GND), U5.2 (GND), U5.4 (-)
G_Q1: Q1.1 (G), R3.2, R12.1
G_Q2: Q2.1 (G), R4.2, R13.1
ISNS: C7.2, C8.2, Q1.2 (S), Q2.2 (S), R12.2, R13.2, RS1.1, U2.4 (GND), U2.5 (GND), U5.3 (+)
LED_A: LED1.2 (A), R11.2
LED_CTL: R11.1, U1.10 (PB1)
NTC: C17.1, R9.2, TH1.1, U1.4 (PA6)
PWM: R6.1, TP3.1, U1.11 (PB0), U2.2 (INPUT)
SNUB: C20.1, R16.2
SW: D2.1 (A), D2.3 (A), J4.1, Q1.3 (D), Q2.3 (D), R16.1, TP8.1
TRIG: C15.1, R7.1, R8.2, U1.5 (PA7)
TRIG_PAD: D3.1 (A1), J5.1, R8.1
UPDI: J6.2, U1.16 (~RESET/PA0)
VBAT: C1.1, C2.1, C3.1, C4.1, C5.1, C6.1, D1.1 (K), D2.2 (K), D4.2 (A), J1.1, J3.1, R1.1
VDRV: C7.1, C8.1, C10.1, C11.1, R14.1, TP2.1, U2.1 (VDD), U2.8 (VDD), U3.1 (OUT), U4.1 (VI)
VFB: R14.2, R15.1, U3.2 (FB)
VREG_IN: C9.1, D4.1 (K), U3.5 (EN), U3.8 (IN)
VSNS: C16.1, R1.2, R2.1, TP6.1, U1.2 (PA4)

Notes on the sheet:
5S BLOWER CONTROLLER - REV C REFERENCE - NOT APPROVED TO ORDER
External fuse REQUIRED in B+ battery lead; select after measured current and I2t review.
Gate driver GND returns to ISNS source bus (Kelvin, below shunt current path).
R16/C20 snubber DNP until switch-node transient is measured.
Trigger input: closing external switch to GND pulls TRIG low (active-low).
VDRV = 1.173V x (1 + R14/R15) = 10.0V nominal.

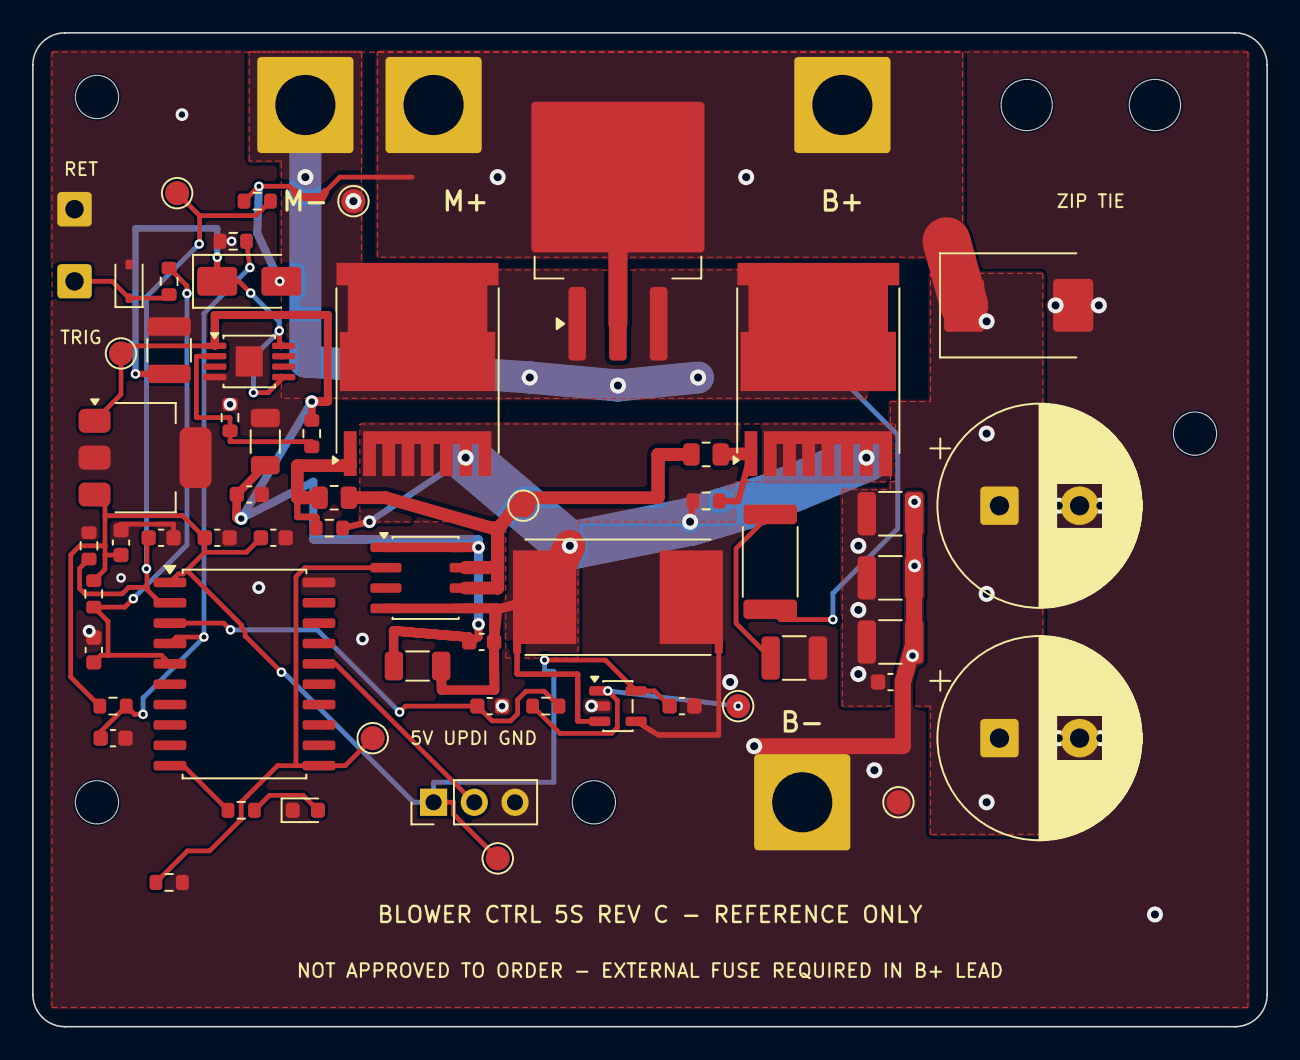
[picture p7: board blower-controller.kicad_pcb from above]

Board: 2 copper layers, 77.0 x 62.0 mm, 70 parts (0 on the bottom side), 22 nets.

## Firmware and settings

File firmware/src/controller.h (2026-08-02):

#pragma once

enum class State {
    OFF,
    ARMING,
    SOFT_START,
    RUN,
    OVERCURRENT,
    UNDERVOLTAGE,
    OVERTEMPERATURE,
    INPUT_FAULT,
    FAULT_LATCHED,
};

struct Inputs {
    // Logical request after the HAL has debounced and inverted the board's
    // active-low TRIG pin. true always means "motor requested" here.
    bool trigger = false;
    float voltage = 0.0f;
    float current = 0.0f;
    float temperature = 0.0f;
};

class Controller {
  public:
    State state = State::OFF;
    State fault_reason = State::OFF;
    float duty = 0.0f;

    void reset();
    void step(const Inputs& inputs, float dt_seconds);

  private:
    void trip(State reason);
    bool can_clear_fault(const Inputs& inputs) const;
};

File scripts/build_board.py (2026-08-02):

"""Single source of truth for the 5S blower controller reference revision (Rev C).

Generates BOTH hardware/blower-controller.kicad_sch and .kicad_pcb from one
connectivity table.  Manual edits to the KiCad files are NOT the workflow;
edit this script and regenerate.  Deterministic (fixed uuid5 seeds).

Run with KiCad's bundled interpreter:
    "C:/Program Files/KiCad/10.0/bin/python.exe" scripts/build_board.py

The default build reproduces the accepted route by generating the validated
power-stage base, importing ``hardware/routing/revC-freerouting.ses``, and
applying the explicit post-route repairs in
``scripts/repair_freeroute_candidate.py``.  ``--legacy-full-routing`` retains
the earlier hand-authored full-route table only for comparison.

Verified component data (datasheet review 2026-08-01/02):
- Q1/Q2  IPT015N10N5ATMA1  100V 1.5mOhm max @10Vgs, Qg typ 169nC, TOLL,
         pin1=G pins2-8=S tab=D (KiCad fp pads 1=G 2=S 3=D). LCSC C108964.
- D2     STPS41H100CG-TR   100V 2x20A Schottky, D2PAK, 1=A 2/tab=K 3=A.
- D1     SMDJ33A           33V standoff, Vc 53.3V @56.3A, 3000W, SMC, unidir.
- U2     TC4422AVOA        4.5-18V (abs 20V), 10A pk, SOIC-8:
         1=VDD 2=IN 3=NC 4=GND 5=GND 6=OUT 7=OUT 8=VDD. LCSC C37183.
- U3     TPS7A4001DGNR     7-100V in, 50mA, FB=1.173V typ, MSOP-8 PowerPAD:
         1=OUT 2=FB 3=NC 4=GND 5=EN 6=NC 7=NC 8=IN, EP=GND. LCSC C55006.
- U4     MCP1703A-5002E/DB 16V in, 250mA, SOT-223: 1=VIN 2=GND(tab) 3=VOUT.
- U1     ATTINY1616-SNR    SOIC-20: 1=VDD 20=GND 16=UPDI 11=PB0(TCA0 WO0)
         10=PB1 2=PA4/AIN4 3=PA5/AIN5 4=PA6/AIN6 5=PA7/AIN7. LCSC C614136.
- U5     INA180A2IDBVR     gain 50, CM -0.2..26V, SOT-23-5:
         1=OUT 2=GND 3=IN+ 4=IN- 5=VS. LCSC C192764.
- RS1    WSR32L000FEA      2mOhm 1% 3W metal strip, Kelvin by split-pad layout.
- C1/C2  UPW1J471MHD       470uF 63V 12.5x25mm P5 low-Z, 1.72A @100kHz.
- C3-C5  C3225X7S2A475K200AE  4.7uF 100V X7S 1210.
- TH1    NCP18XH103F03RB   NTC 10k B3380 0603. LCSC C13564.
- D3     PESD5V0S1BA       bidirectional ESD, SOD-323. LCSC C19224.
- D4     S1M (onsemi)      1000V 1A SMA. LCSC C232826.
- LED1   19-217/GHC-YR1S2/3T green 0603. LCSC C72043 (/6T C2986059 stocked).

VDRV = 10V from TPS7A4001: Vout = 1.173*(1+R14/R15), R14=97.6k R15=13.0k
       -> 9.98V nominal.  Gate driver return is Kelvin-tied to the MOSFET
       source bus (ISNS) so gate current does not cross the shunt.
"""
import subprocess
import sys
from pathlib import Path

ROOT = Path(__file__).parents[1]
sys.path.insert(0, str(ROOT / "scripts"))

import kicadlib  # noqa: E402
import kicad_sch_writer as sw  # noqa: E402

SYMDIR = r"C:\Program Files\KiCad\10.0\share\kicad\symbols"
FPDIR = Path(r"C:\Program Files\KiCad\10.0\share\kicad\footprints")
KICAD_CLI = r"C:\Program Files\KiCad\10.0\bin\kicad-cli.exe"
OUT_SCH = ROOT / "hardware" / "blower-controller.kicad_sch"
OUT_PCB = ROOT / "hardware" / "blower-controller.kicad_pcb"
OUT_PRO = ROOT / "hardware" / "blower-controller.kicad_pro"
PROJ_SYM = ROOT / "hardware" / "symbols" / "blower_project.kicad_sym"
ROUTING_SESSION = ROOT / "hardware" / "routing" / "revC-freerouting.ses"


def enforce_release_drc_severities():
    """Keep manufacturing-relevant placement/routing checks enabled.

    pcbnew can rewrite the project file with KiCad's default ignored severities
    while saving a generated board.  Reinstate the release policy immediately
    before the command-line DRC so reproducibility cannot hide these checks.
    """
    project = OUT_PRO.read_text(encoding="utf-8")
    replacements = {
        '"missing_courtyard": "ignore"': '"missing_courtyard": "error"',
        '"track_not_centered_on_via": "ignore"': (
            '"track_not_centered_on_via": "error"'
        ),
    }
    for old, new in replacements.items():
        project = project.replace(old, new)
    OUT_PRO.write_text(project, encoding="utf-8")

# --------------------------------------------------------------- nets
# Every net used by more than one pin.
NETS = [
    "VBAT", "GND", "SW", "ISNS", "GATE", "G_Q1", "G_Q2", "PWM",
    "VREG_IN", "VDRV", "VFB", "+5V", "VSNS", "TRIG_PAD", "TRIG",
    "CUR", "CUR_ADC", "NTC", "UPDI", "LED_A", "LED_CTL", "SNUB",
]
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

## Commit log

2026-08-01 Create reference 5S blower controller project
    [blower-controller.kicad_pcb, blower-controller.kicad_sch]
2026-08-01 Add KiCad export package and preliminary Gerbers
    [BOM.csv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]
2026-08-01 Ignore KiCad local session files
2026-08-01 Refresh preliminary KiCad manufacturing outputs
    [blower-controller-B_Cu.gbl, blower-controller-Edge_Cuts.gm1, blower-controller-F_Cu.gtl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]
2026-08-01 Include preliminary PCBWay ZIP artifact
2026-08-02 Add reproducible Rev C PCBWay review package
    [BOM.csv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]
